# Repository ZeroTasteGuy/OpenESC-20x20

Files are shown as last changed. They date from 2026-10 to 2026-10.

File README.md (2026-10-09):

# OpenESC-20x20

A 4-in-1 sensorless BLDC ESC for the **20 x 20 mm** FPV stack hole pattern: four
independent motor controllers, each with its own MCU, gate driver and six
MOSFETs, running AM32 and taking DShot over a standard 8-pin connector.

> **Status: placement only.** All parts are placed, but there is **no copper and
> no routing**. The board has not been routed, fabricated or tested. Do not
> order it. See [Known issues](#known-issues).

<p>
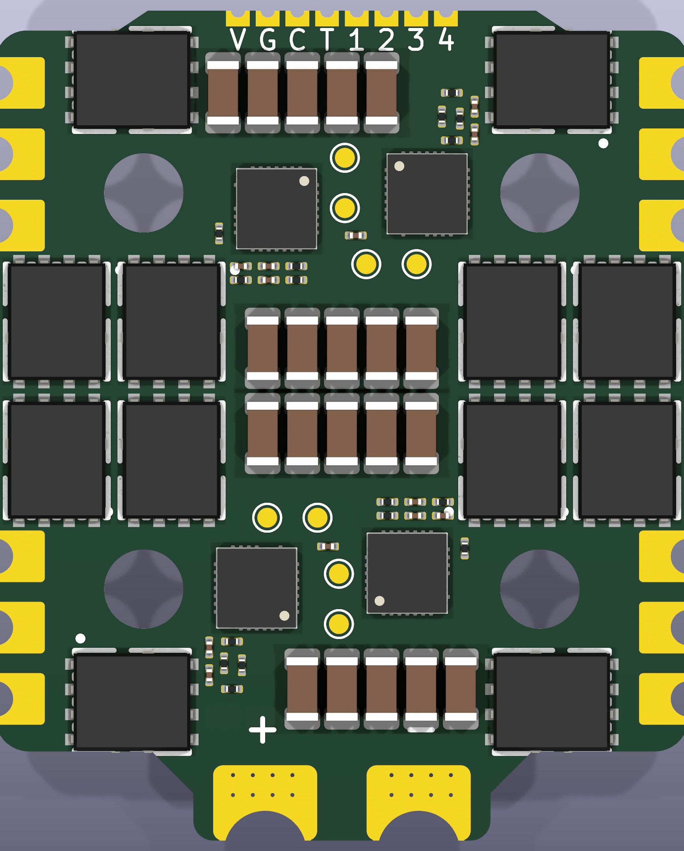
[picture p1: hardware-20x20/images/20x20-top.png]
OpenESC-20x20 top

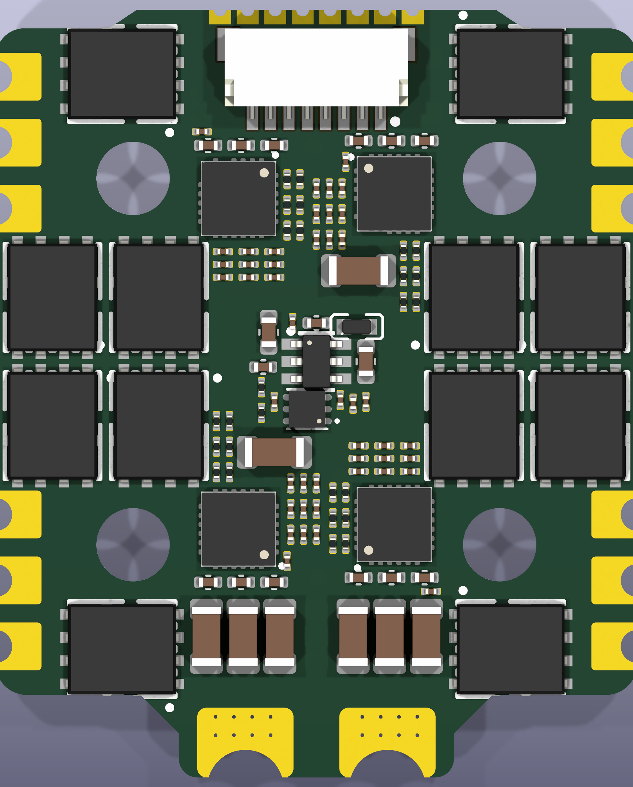
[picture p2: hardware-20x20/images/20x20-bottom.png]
OpenESC-20x20 bottom

</p>

3D views: [top](hardware-20x20/images/20x20-3d-top.png),
[bottom](hardware-20x20/images/20x20-3d-bottom.png).

This is a new PCB layout of the circuit from
[OpenDrone-hw/OpenESC-30x30](https://github.com/OpenDrone-hw/OpenESC-30x30)
(CERN-OHL-S-2.0, maintainer [@Just4Stan](https://github.com/Just4Stan)). The
outline and layout are new, and this board **does not include the current-sense
circuit** (see below); the schematic was edited to match. It is not an official
OpenDrone or Incutec release and is not covered by the upstream OSHWA
certification.

## What changed from the 30x30

| | 30x30 (upstream) | 20x20 (this layout) |
|---|---|---|
| Mounting holes | 30.5 mm pattern | 20 x 20 mm, 4 mm unplated, no copper ring |
| Board size | 30.5 mm class | about 35 x 42 mm including battery tab |
| Layers / copper | 6 layers, 1.6 mm, 2 oz outer / 1 oz inner | same (rules in `4in1.kicad_pro` and `4in1.kicad_dru`) |
| Motor pads | per upstream | corner groups, 3 pads per motor, no notch mid-edge |
| MOSFETs | 24 | 24, as 12 stacked pairs (high side top, low side bottom) |
| Bulk ceramic 1206 | 52 | **28**, on top near the MOSFETs |
| Battery pads | per upstream | two castellated pads on a tab, 4 mm wide x 1.5 mm deep |
| MCU, drivers, critical passives | per upstream | bottom side |
| Programming pads | per upstream | 2.54 mm pitch with hand-rework clearance |
| Current sense | INA186 + 2 shunts, board level | **not on this board** |

Fewer bulk capacitors means less local ripple filtering; install the 470 uF 50 V
electrolytic on the battery leads. Current capacity of this layout is **not**
validated; four channels at 60 A through a board this size is not realistic. See
[hardware-20x20/docs/DESIGN-NOTES.md](hardware-20x20/docs/DESIGN-NOTES.md).

## Specifications (circuit, as upstream)

| | |
|---|---|
| Firmware | AM32 |
| ESC protocol | DShot, bidirectional |
| Telemetry | Extended DShot |
| Input | 2-8S LiPo (6.0-33.6 V) |
| BEC | None |
| Rated current | 60 A / channel in the 30x30 design; **not established for this layout** |

## Architecture

Four independent channels share one power input and one connector. Per channel:
an **AT32F421G8U7** (Cortex-M4, QFN-28) drives an **NSG2065Q** three-phase
half-bridge gate driver, which drives six **SP40N01GHNK** MOSFETs, two per
phase. One channel is drawn once in `ESC.kicad_sch` and instantiated four times.

**There is no current sensing on this board.** The upstream design has a board-level
INA186A3IDCKR across two 0.2 mOhm shunts, reported as `/CURR`. That circuit is
not placed here and was removed from the schematic: U12, Rsense1, Rsense2, R89,
R90, C40, C41, C42, C94 and R73. No per-phase shunts were added either. The
battery pad (U3 pin 1) now connects straight to `+BATT`. `/CURR` (connector pin 3)
is kept as a net but is not driven.

## Power

```
Battery + (2S-8S) ─► +BATT
+BATT ─┬─► MOSFET drains, motor phases
       └─► LMR54406DBVR buck ─► +10V ─┬─► 4x gate driver
                                      └─► TLV76733DRVR ─► +3V3 ─► 4x MCU
```

## Key parts

| Function | Ref | Part | LCSC | Note |
|---|---|---|---|---|
| Motor MCU, x4 | U2, U5, U7, U9 | AT32F421G8U7, QFN-28 | C2765098 | One per channel |
| Gate driver, x4 | U4, U6, U8, U10 | NSG2065Q, QFN-24 | C41414478 | Standard footprint, alternatives exist |
| Power MOSFET, x24 | Q1-Q24 | SP40N01GHNK, PDFN-8L 5x6 | C22385416 | 40 V, 6 per channel; standard 5x6 DFN footprint |
| Buck | U13 | LMR54406DBVR, SOT-23-6 | C5219316 | 1.1 MHz, 0.6 A; FB 115k/10k against 0.8 V for 10.0 V out |
| Buck inductor | U14 | FTC160808S4R7MBCA | C46594347 | 4.7 uH |
| LDO | U15 | TLV76733DRVR, WSON-6 | C2848334 | +10 V to +3V3 |
| Connector | J1 | SM08B-SRSS-TB, JST SH 8-pin | C160407 | Also broken out as castellated pads |
| Bulk electrolytic | / | 470 uF 50 V | / | Installed by the user on the battery leads |
| Bulk ceramic | see PCB | 4.7 uF 1206, X5R 50 V | C380366 | 28 fitted on this layout |

## Connectors and I/O

Betaflight standard 8-pin:

| Pin | Net | Function |
|---|---|---|
| 1 | +BATT | Battery positive |
| 2 | GND | Ground |
| 3 | /CURR | Current sense output; **not driven on this board** (no INA186 fitted) |
| 4 | unconnected | See below |
| 5 | /M1 | DShot, channel 1 |
| 6 | /M2 | DShot, channel 2 |
| 7 | /M3 | DShot, channel 3 |
| 8 | /M4 | DShot, channel 4 |

Pin 4 is the dedicated telemetry pin in the Betaflight 8-pin standard and is
intentionally left unconnected: ESC to FC telemetry rides the motor signal lines
over bidirectional extended DShot instead.

## Layout rules

Bulk decoupling on +BATT and GND exists on the PCB without matching schematic
symbols. That is a deliberate board-only bank. Do not run update-from-schematic
without checking what it would delete.

## Firmware

[AM32](https://github.com/am32-firmware/AM32). Load the bootloader
(`AM32_F421_BOOTLOADER_PB4_V19.hex`) first with an ST-LINK, then flash and
configure the firmware in-browser at [am32.ca](https://am32.ca). Works with
Betaflight and any other DShot-capable flight controller.

## Repository

| | |
|---|---|
| Designed in | KiCad 10 |
| KiCad project | `hardware-20x20/4in1.kicad_pro` (name kept from upstream) |
| Schematics | `hardware-20x20/4in1.kicad_sch` (power, connectors, board block U3, castellated strip J2) plus `ESC.kicad_sch` (one channel, instantiated 4x, unchanged from upstream) |
| Board | `hardware-20x20/4in1.kicad_pcb`, 6 layers, 1.6 mm, 2 oz outer / 1 oz inner copper |
| Board setup | 0.09 mm clearance and track, 0.16 mm on outer layers (2 oz), via 0.35 on 0.20 drill |
| Design rules | `hardware-20x20/4in1.kicad_dru` |
| Local libraries | `components.kicad_sym`, `4in1ESC-30x30.pretty/`, `4in1ESC-30x30.3dshapes/` (only the models in use), inherited from upstream |
| Fab config | `hardware-20x20/fabrication-toolkit-options.json` |
| Renders | `hardware-20x20/images/` |
| Design notes | `hardware-20x20/docs/DESIGN-NOTES.md` |
| Last DRC | `hardware-20x20/docs/drc-v15-placement.json` |
| Placement scripts | `hardware-20x20/tools/` (provenance only, see its README) |
| License | CERN-OHL-S-2.0, see [LICENSE](LICENSE) |

## Checks

```sh
kicad-cli sch erc hardware-20x20/4in1.kicad_sch
kicad-cli pcb drc --schematic-parity --refill-zones hardware-20x20/4in1.kicad_pcb
```

Last DRC run (`docs/drc-v15-placement.json`, without schematic parity): no
clearance or annular-ring errors after the castellated pad fix (the project has
`copper_edge_clearance` set to ignore; with it on, 4 hits remain on the battery
tab, see `hardware-20x20/docs/DESIGN-NOTES.md`); 29
`lib_footprint_mismatch` (to be cleared by re-saving footprints from KiCad
against the local library); 472 unconnected items because nothing is routed.

With schematic parity and ERC (KiCad 10, run on this schematic and board):

- Parity: every schematic part is on the board, and J2 matches except for its
  value and BOM flag (see Known issues). 25 footprints are
  board-only (the CB bulk caps, kept board-only as upstream does). 16
  `net_conflict` notes on IC pads and a J2 pad 4 net name are inherited from
  upstream and the board's footprints. About 146 field mismatches are metadata
  only (Manufacturer fields blank on the board).
- ERC: 18 `pin_not_driven` errors (was 24 upstream) and 4
  `power_pin_not_driven` (was 3). Two of those four appeared because the removed
  U3 power-output pins no longer drive `+BATT` and `GND`; adding a PWR_FLAG on
  each net clears them.

KiCad files cannot be merged. Close KiCad before any scripted write to a KiCad
file, and do not text-edit `.kicad_sch`, `.kicad_pcb` or `.kicad_dru`.

## Known issues

- **Schematic edits to finish.** Add a PWR_FLAG on `+BATT` and `GND` to clear two
  new ERC errors, and set J2's value to "Castellated FC pads" with Exclude from
  BOM ticked so it matches the board footprint exactly.
- **No current sensing.** Removed on purpose (see Architecture). The ESC reports no
  current telemetry; `/CURR` is undriven.
- No copper, planes, vias or tracks. Routing, power-plane design and a current
  and thermal check are all still to do.
- The castellated pads need the fab to accept half-plated holes of this size.
- Some small parts sit in tight clusters (0.2 to 0.3 mm gaps). An earlier
  routing attempt on a related layout failed mostly on boxed-in pads, so expect
  to spread parts or route by hand.
- Silkscreen text may still carry upstream naming; review before any fab export.

## Revisions

| Rev | Date | Change |
|---|---|---|
| v15 | 2026-10-08 | Placement only: 28 bulk caps with fab-safe spacing, battery castellation pads run to the edge, J2 silk labels 1.0 mm. No copper. |
| v15a | 2026-10-08 | Castellated motor and signal pads widened to 5 mm (clears the annular-width DRC errors). Schematic matched to the board: current-sense circuit removed, castellated strip J2 added, U3 board block redrawn as the real outline with only the pins that have pads. |

Upstream revision history (30x30 Rev1 to Rev3.3) is in the
[OpenESC-30x30 repository](https://github.com/OpenDrone-hw/OpenESC-30x30).

## Credit and licence

CERN-OHL-S-2.0, same as upstream. Original circuit and 30x30 design by the
OpenDrone / Incutec team, maintainer @Just4Stan. The 20x20 board layout is a
modified version; changes are limited to PCB outline and placement as described
above. Upstream branding, badges and certification do not carry over to this
layout.

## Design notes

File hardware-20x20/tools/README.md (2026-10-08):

# tools

Python and shell scripts used to generate and check the 20x20 placement
(outline and pads, MOSFET sites, IC and bulk-cap placement, small-part
optimiser, DRC wrapper, an experimental grid router and a copper-path resistance
solver).

Provenance only. They were developed on Windows against `kicad-cli` from KiCad
10 and expect local working copies and intermediate boards that are not in this
repository (for example `../hardware-alt/4in1.kicad_pcb` as the source layout).
Each script rewrites KiCad board text, so run them on copies, never on files in
`hardware-20x20/`. Upstream rules apply: close KiCad before
writing any KiCad file.

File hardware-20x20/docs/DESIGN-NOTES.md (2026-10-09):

# 20x20 layout: design notes

Why the board looks the way it does, and what is known and unknown. Revision
history of the layout lives in git; this file is the intent.

## Goals

- Fit the existing OpenESC circuit on a 20 x 20 mm stack pattern, about 35 x 42 mm.
- Layout in the style of common 20x20 4-in-1 ESCs: motor pads in corner groups
  (3 per motor), no notch in the middle of the long edges, stacked MOSFET pairs.
- Keep the circuit the same except where the layout forced a change (see below).

## Placement

- **Holes:** 4 mm unplated at (+-10, +-10) mm. A 6 mm rubber-grommet zone around
  each hole keeps small parts out.
- **MOSFETs:** 12 sites, each a stacked pair on the same x/y (high side on top,
  low side on the bottom): 4 corner pairs (phase A) and 8 strip pairs (phases B
  and C, inner and edge columns). Upper-half sites are rotated 0 degrees, lower
  half 180 degrees.
- **Bottom side:** MCUs, gate drivers, buck, LDO and critical passives (gate
  resistors, bootstrap and supply decoupling).
- **Top side:** MOSFETs, 28 bulk 1206 capacitors, test points and a few
  non-critical parts.
- **Symmetry:** the two half-boards are 180 degree twins.
- **Battery tab:** two castellated pads 4 mm wide and 1.5 mm deep with rounded
  tab corners; a bulk-cap row sits directly above it.
- **Castellation convention:** the motor pads (U3 pads 12 to 23) and the J2 strip
  are centred on their plated hole, with the hole on the board edge and no drill
  offset. The pads are 5 x 2.6 mm (motor) and 1.2 x 1.6 mm (J2), so 2.5 mm and
  0.8 mm of copper lie inside the board; the outer half hangs past the outline
  and is milled away by the fab. An earlier version put the pad on the edge with
  the drill offset inboard, which missed the Edge.Cuts half-hole notch and gave
  zero annular width. The battery castellations were already consistent (hole
  centre 0.58 mm outside the edge, 1.5 mm deep notch).
- **Known DRC note:** the project sets `copper_edge_clearance` to ignore. With it
  enabled there are 4 hits on the battery tab, where the pad copper meets the
  outline beside each notch (near x 69.1 and 73.725, y 70.05). Accepted for now;
  confirm with the fab.
- **Keep-outs used:** small ICs and passives at least 3 mm from motor and battery
  pads and 2 mm from the board edge. MOSFETs, the JST connector and 1206 caps may
  sit closer. Bulk-cap pad gaps are at least 0.2 mm for fab safety.
- **No current sensing at all.** The board-level INA186 (U12), its two shunts
  (Rsense1, Rsense2) and the input network (R89, R90, C40, C41, C42, plus C94 and
  R73) are not on the PCB, and per-phase shunts were not wanted either. They
  were removed from the schematic so it matches the board.
- **Schematic matched to the board:** castellated strip J2 added (pins +BATT,
  GND, CURR, unused, M1 to M4); the U3 board block lost the pins that no longer
  have pads (3 to 11) and was redrawn with the real board outline (chamfered
  top strip, bottom battery tab, four mounting holes); the battery pad (U3 pin 1)
  joins `+BATT` directly where the shunts used to sit.

## Findings

- **Bottom free area is the bottleneck.** About 391 mm2 of 1345 mm2 is free for
  small parts after MOSFETs, pad keep-outs, grommet zones and the edge band.
- **Copper-only path resistance** (estimated on an earlier placement with power
  copper, ESC1, source-to-pad / pad-to-drain, mOhm): phase A 0.18 / 0.14,
  B 0.06 / 0.03, C 0.61 / 0.48. Worst point: low-side ground path of phase B
  (about 2 mOhm, no ground vias yet) and the narrow phase-C lane between hole and
  MOSFET row. This was **not** repeated on the final placement.
- **Current capacity:** lane necks reached about 45 A/mm at 40 A in an earlier
  trial; about 8 to 10 A/mm is comfortable for 2 oz outer copper. Do not expect
  four channels at 60 A.
- **Signal routing:** an automatic grid router completed about a third of the
  links on the related layout, and most failures were pads boxed in by
  neighbours. Spacing, not copper weight, is the limit.

## To do before this can be a real board

0. Add a PWR_FLAG on `+BATT` and `GND`, set J2's value and BOM flag to match the
   board, then re-run ERC and DRC with schematic parity.
1. Power copper: planes, phase copper, via sets, ground vias at low-side sources.
2. Signal routing, mostly by hand.
3. Re-run DRC with schematic parity and ERC, resolve `lib_footprint_mismatch`.
4. Resistance and thermal check on the routed board.
5. Confirm castellation capability with the intended fab.
6. Rename the archive in `fabrication-toolkit-options.json`, review silkscreen.
7. Bring-up with a current-limited supply before any motor.

## Regenerating

`tools/` holds the scripts that produced the placement. They were run against
local working copies that are not in this repository, so treat them as
documentation of the method rather than a reproducible build. See
`tools/README.md`.

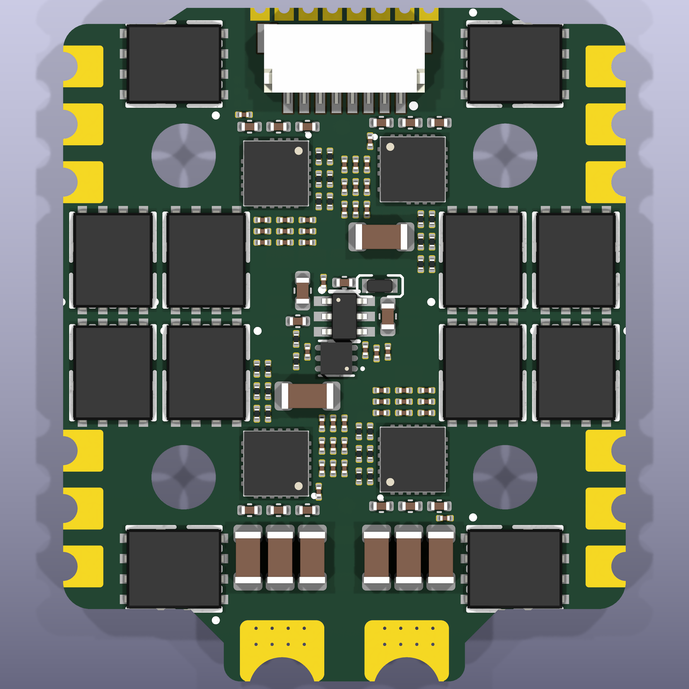
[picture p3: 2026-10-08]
hardware-20x20/images/20x20-3d-bottom.png

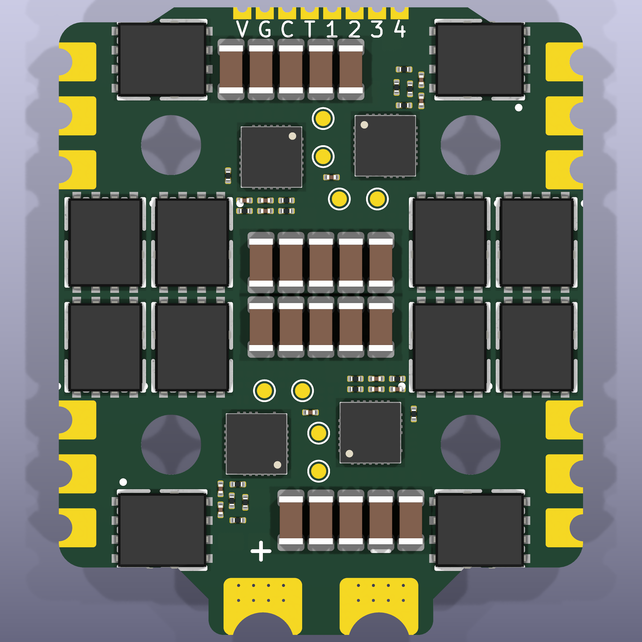
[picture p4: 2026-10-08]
hardware-20x20/images/20x20-3d-top.png

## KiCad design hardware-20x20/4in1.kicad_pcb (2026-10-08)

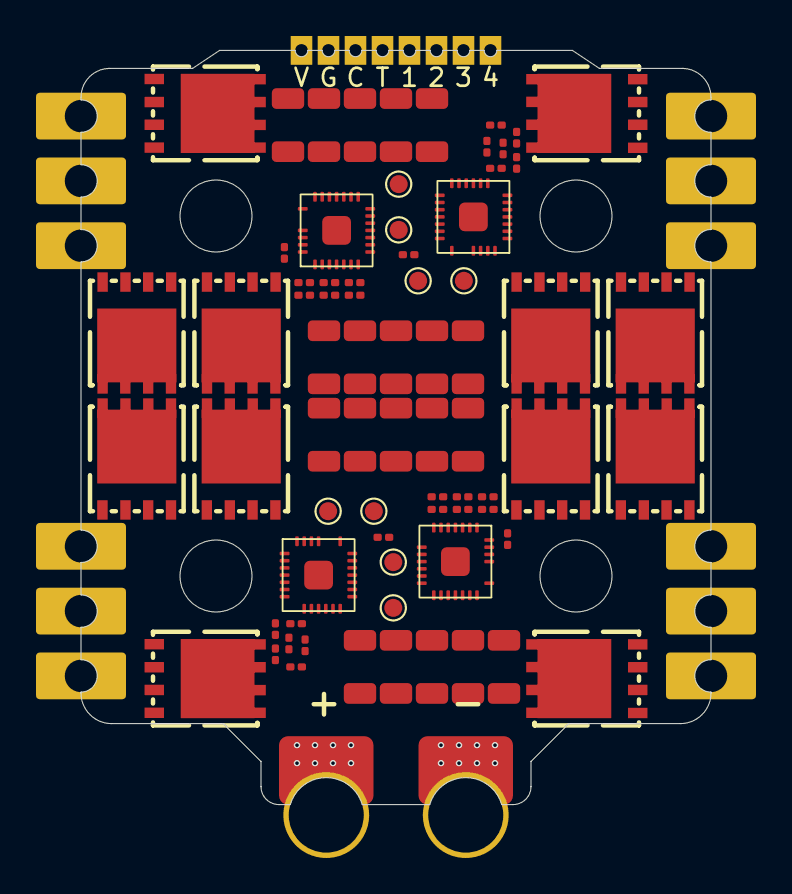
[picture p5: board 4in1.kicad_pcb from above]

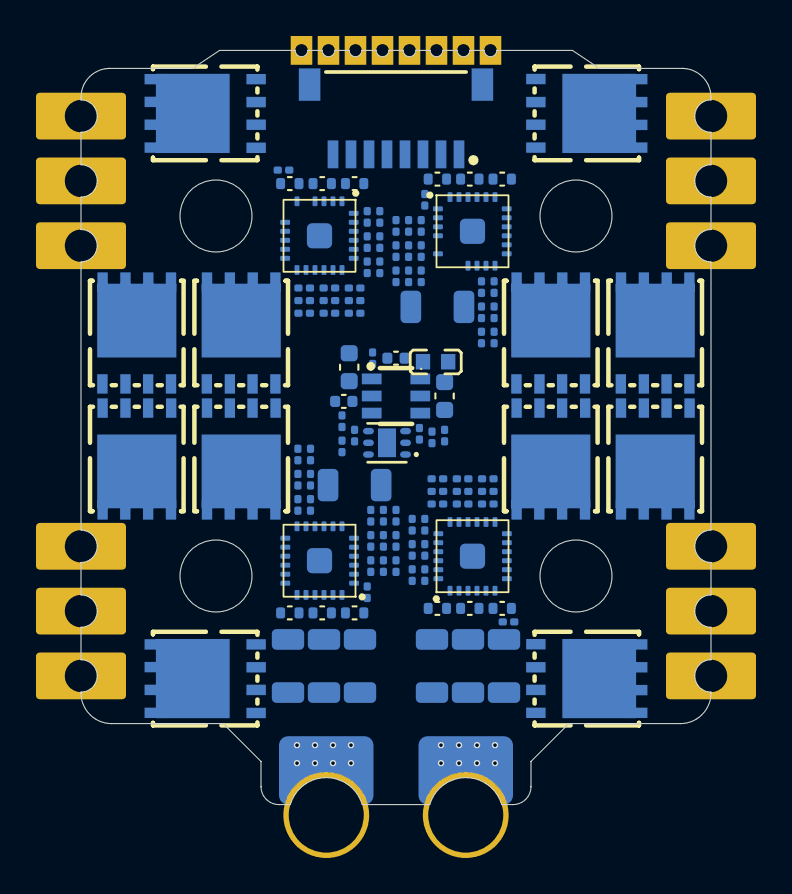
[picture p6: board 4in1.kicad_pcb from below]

Board: 6 copper layers, 35.0 x 41.9 mm, 189 parts (115 on the bottom side), 148 nets, no tracks yet.

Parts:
C2, C3, C6: 4.7uF; C_1206_3216Metric
C4, C51: 22uF; C_0402_1005Metric
C32, C33, C34, C35, C36, C37, C38, C39, C53, C56, C62, C67: 100nF; C_0402_WIDE
C47, C86: 22uF; C_0603_1608Metric
C48, C49, C50, C52, C54, C55, C57, C58, C59, C60, C61, C63, C64, C65, C66, C68, C74, C75, C76, C81, C93: 100nF; C_0201_0603Metric
CB1, CB2, CB3, CB4, CB5, CB6, CB7, CB8, CB9, CB10, CB11, CB12, CB13, CB15, CB19, CB20, CB21, CB25, CB26, CB28, CB29, CB30, CB31, CB32, CB33: 4.7uF; C_1206_3216Metric
J1: SM08B-SRSS-TB; JST_SM08B-SRSS-TB
J2: Castellated FC pads; Castellated_8x1.50
Q1, Q2, Q3, Q4, Q5, Q6, Q7, Q8, Q9, Q10, Q11, Q12, Q13, Q14, Q15, Q16, Q17, Q18, Q19, Q20, Q21, Q22, Q23, Q24: SP40N01GHNK; PDFN-8L_L6.0-W5.0-P1.27
R10, R12, R13, R15, R25, R27, R28, R30, R31, R33, R34, R36, R46, R48, R49, R51, R52, R54, R64, R66, R67, R69, R70, R72: 10k; C_0201_0603Metric
R11, R14, R26, R29, R32, R35, R47, R50, R53, R65, R68, R71: 1k; C_0201_0603Metric
R18, R19, R21, R22, R40, R41, R58, R59, R121: 10k; R_0201_0603Metric
R20, R39, R57, R87: 220R; R_0201_0603Metric
R23, R24, R37, R38, R42, R43, R44, R45, R55, R56, R60, R61, R62, R63, R74, R75, R76, R77, R78, R79, R80, R81, R82, R83: 15R; R_0201_0603Metric
R84, R85, R86, R88: 10R; R_0201_0603Metric
R120: 115k; R_0201_0603Metric
TP1, TP2, TP3, TP4, TP5, TP6, TP7, TP8: TestPoint; TestPoint_Pad_D1.0mm
U2, U5, U7, U9: AT32F421G8U7; QFN-28_L4.0-W4.0-P0.40-TL-EP2.4
U3: 4in1ESC30x30
U4, U6, U8, U10: NSG2065Q; QFN-24_L4.0-W4.0-P0.50-TL-EP2.8
U13: LMR54406DBVR; SOT-23-6_L2.9-W1.6-P0.95-LS2.8-BR
U14: FTC160808S4R7MBCA; IND-SMD_L1.6-W0.8_FTC160865SR47MBCA
U15: TLV76733DRVR; WSON-6_L2.0-W2.0-P0.65-TL-EP

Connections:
+3V3: C4.2, C49.1, C51.2, C55.1, C61.1, C66.1, C81.1, C93.1, R18.2, R21.2, R40.2, R58.2, R84.2, R85.2, R86.2, R88.2, U2.17 (VDD), U5.17 (VDD), U7.17 (VDD), U9.17 (VDD), U15.1 (OUT), U15.2 (FB/SNS)
+10V: C47.1, C57.1, C58.1, C63.1, C68.1, C76.1, C86.1, R120.1, U4.4 (VCC), U6.4 (VCC), U8.4 (VCC), U10.4 (VCC), U14.2, U15.4 (EN), U15.6 (IN)
+BATT: C2.1, C3.1, C6.1, C74.1, CB1.1, CB2.1, CB3.1, CB4.1, CB5.1, CB6.1, CB7.1, CB8.1, CB9.1, CB10.1, CB11.1, CB12.1, CB13.1, CB15.1, CB19.1, CB20.1, CB21.1, CB25.1, CB26.1, CB28.1, CB29.1, CB30.1, CB31.1, CB32.1, CB33.1, J1.1, J2.1 (VCC), Q1.3 (D), Q6.3 (D), Q7.3 (D), Q8.3 (D), Q9.3 (D), Q10.3 (D), Q13.3 (D), Q16.3 (D), Q17.3 (D), Q18.3 (D), Q19.3 (D), Q20.3 (D), U3.1, U13.4 (EN), U13.5 (VIN)
/CURR: J1.3, J2.3 (CUR)
/ESC1/AH: U2.20 (PA10), U4.22 (HIN1)
/ESC1/AL: U2.15 (PB1), U4.1 (LIN1)
/ESC1/BH: U2.19 (PA9), U4.23 (HIN2)
/ESC1/BL: U2.14 (PB0), U4.2 (LIN2)
/ESC1/CH: U2.18 (PA8), U4.24 (HIN3)
/ESC1/CL: U2.13 (PA7), U4.3 (LIN3)
/ESC1/FBA: R25.1, R26.2, R27.2, U2.6 (PA0)
/ESC1/FBB: R28.2, R29.2, R30.2, U2.10 (PA4)
/ESC1/FBC: R31.2, R32.2, R33.2, U2.11 (PA5)
/ESC1/FBCOMMON: R25.2, R28.1, R31.1, U2.7 (PA1)
/ESC1/GHA: R76.1, U4.19 (HO1)
/ESC1/GHB: R55.1, U4.16 (HO2)
/ESC1/GHC: R23.1, U4.13 (HO3)
/ESC1/GLA: R80.1, U4.11 (LO1)
/ESC1/GLB: R62.1, U4.10 (LO2)
/ESC1/GLC: R42.1, U4.9 (LO3)
/ESC1/MotorA: C53.1, Q1.1 (S), Q2.3 (D), R27.1, U3.23, U4.18 (VS1)
/ESC1/MotorB: C32.1, Q6.1 (S), Q11.3 (D), R30.1, U3.22, U4.15 (VS2)
/ESC1/MotorC: C36.1, Q16.1 (S), Q21.3 (D), R33.1, U3.21, U4.12 (VS3)
/ESC1/vdda: C48.1, R84.1, U2.5 (VDDA)
/ESC2/AH: U5.20 (PA10), U6.22 (HIN1)
/ESC2/AL: U5.15 (PB1), U6.1 (LIN1)
/ESC2/BH: U5.19 (PA9), U6.23 (HIN2)
/ESC2/BL: U5.14 (PB0), U6.2 (LIN2)
/ESC2/CH: U5.18 (PA8), U6.24 (HIN3)
/ESC2/CL: U5.13 (PA7), U6.3 (LIN3)
/ESC2/FBA: R10.1, R11.2, R12.2, U5.6 (PA0)
/ESC2/FBB: R13.2, R14.2, R15.2, U5.10 (PA4)
/ESC2/FBC: R34.2, R35.2, R36.2, U5.11 (PA5)
/ESC2/FBCOMMON: R10.2, R13.1, R34.1, U5.7 (PA1)
/ESC2/GHA: R77.1, U6.19 (HO1)
/ESC2/GHB: R56.1, U6.16 (HO2)
/ESC2/GHC: R24.1, U6.13 (HO3)
/ESC2/GLA: R81.1, U6.11 (LO1)
/ESC2/GLB: R63.1, U6.10 (LO2)
/ESC2/GLC: R43.1, U6.9 (LO3)
/ESC2/MotorA: C56.1, Q3.3 (D), Q7.1 (S), R12.1, U3.20, U6.18 (VS1)
/ESC2/MotorB: C33.1, Q8.1 (S), Q12.3 (D), R15.1, U3.19, U6.15 (VS2)
/ESC2/MotorC: C37.1, Q17.1 (S), Q22.3 (D), R36.1, U3.18, U6.12 (VS3)
/ESC2/vdda: C54.1, R85.1, U5.5 (VDDA)
/ESC3/AH: U7.20 (PA10), U8.22 (HIN1)
/ESC3/AL: U7.15 (PB1), U8.1 (LIN1)
/ESC3/BH: U7.19 (PA9), U8.23 (HIN2)
/ESC3/BL: U7.14 (PB0), U8.2 (LIN2)
/ESC3/CH: U7.18 (PA8), U8.24 (HIN3)
/ESC3/CL: U7.13 (PA7), U8.3 (LIN3)
/ESC3/FBA: R46.1, R47.2, R48.2, U7.6 (PA0)
/ESC3/FBB: R49.2, R50.2, R51.2, U7.10 (PA4)
/ESC3/FBC: R52.2, R53.2, R54.2, U7.11 (PA5)
/ESC3/FBCOMMON: R46.2, R49.1, R52.1, U7.7 (PA1)
/ESC3/GHA: R78.1, U8.19 (HO1)
/ESC3/GHB: R60.1, U8.16 (HO2)
/ESC3/GHC: R37.1, U8.13 (HO3)
/ESC3/GLA: R82.1, U8.11 (LO1)
/ESC3/GLB: R74.1, U8.10 (LO2)
/ESC3/GLC: R44.1, U8.9 (LO3)
/ESC3/MotorA: C62.1, Q4.3 (D), Q13.1 (S), R48.1, U3.15, U8.18 (VS1)
/ESC3/MotorB: C34.1, Q9.1 (S), Q14.3 (D), R51.1, U3.16, U8.15 (VS2)
/ESC3/MotorC: C38.1, Q18.1 (S), Q23.3 (D), R54.1, U3.17, U8.12 (VS3)
/ESC3/vdda: C60.1, R86.1, U7.5 (VDDA)
/ESC4/AH: U9.20 (PA10), U10.22 (HIN1)
/ESC4/AL: U9.15 (PB1), U10.1 (LIN1)
/ESC4/BH: U9.19 (PA9), U10.23 (HIN2)
/ESC4/BL: U9.14 (PB0), U10.2 (LIN2)
/ESC4/CH: U9.18 (PA8), U10.24 (HIN3)
/ESC4/CL: U9.13 (PA7), U10.3 (LIN3)
/ESC4/FBA: R64.1, R65.2, R66.2, U9.6 (PA0)
/ESC4/FBB: R67.2, R68.2, R69.2, U9.10 (PA4)
/ESC4/FBC: R70.2, R71.2, R72.2, U9.11 (PA5)
/ESC4/FBCOMMON: R64.2, R67.1, R70.1, U9.7 (PA1)
/ESC4/GHA: R79.1, U10.19 (HO1)
/ESC4/GHB: R61.1, U10.16 (HO2)
/ESC4/GHC: R38.1, U10.13 (HO3)
/ESC4/GLA: R83.1, U10.11 (LO1)
/ESC4/GLB: R75.1, U10.10 (LO2)
/ESC4/GLC: R45.1, U10.9 (LO3)
/ESC4/MotorA: C67.1, Q5.3 (D), Q19.1 (S), R66.1, U3.12, U10.18 (VS1)
/ESC4/MotorB: C35.1, Q10.1 (S), Q15.3 (D), R69.1, U3.13, U10.15 (VS2)
/ESC4/MotorC: C39.1, Q20.1 (S), Q24.3 (D), R72.1, U3.14, U10.12 (VS3)
/ESC4/vdda: C65.1, R88.1, U9.5 (VDDA)
/M1: J1.5, J2.5 (S1), R20.1
/M2: J1.6, J2.6 (S2), R39.1
/M3: J1.7, J2.7 (S3), R57.1
/M4: J1.8, J2.8 (S4), R87.1
GND: C2.2, C3.2, C4.1, C6.2, C47.2, C48.2, C49.2, C50.2, C51.1, C52.2, C54.2, C55.2, C57.2, C58.2, C59.2, C60.2, C61.2, C63.2, C64.2, C65.2, C66.2, C68.2, C74.2, C76.2, C81.2, C86.2, C93.2, CB1.2, CB2.2, CB3.2, CB4.2, CB5.2, CB6.2, CB7.2, CB8.2, CB9.2, CB10.2, CB11.2, CB12.2, CB13.2, CB15.2, CB19.2, CB20.2, CB21.2, CB25.2, CB26.2, CB28.2, CB29.2, CB30.2, CB31.2, CB32.2, CB33.2, J1.2, J1.P1 (MP1), J1.P2 (MP2), J2.2 (GND), Q2.1 (S), Q3.1 (S), Q4.1 (S), Q5.1 (S), Q11.1 (S), Q12.1 (S), Q14.1 (S), Q15.1 (S), Q21.1 (S), Q22.1 (S), Q23.1 (S), Q24.1 (S), R11.1, R14.1, R19.2, R22.2, R26.1, R29.1, R32.1, R35.1, R41.2, R47.1, R50.1, R53.1, R59.2, R65.1, R68.1, R71.1, R121.2, U2.16 (VSS), U2.29 (VSS), U3.2, U4.6 (COM), U4.25 (COM), U5.16 (VSS), U5.29 (VSS), U6.6 (COM), U6.25 (COM), U7.16 (VSS), U7.29 (VSS), U8.6 (COM), U8.25 (COM), U9.16 (VSS), U9.29 (VSS), U10.6 (COM), U10.25 (COM), U13.2 (GND), U15.3 (GND), U15.5 (GND), U15.7 (EP)
unnamed: Q1.2 (G), R76.2
unnamed: Q2.2 (G), R80.2
unnamed: Q3.2 (G), R81.2
unnamed: Q4.2 (G), R82.2
unnamed: Q5.2 (G), R83.2
unnamed: Q6.2 (G), R55.2
unnamed: Q7.2 (G), R77.2
unnamed: Q8.2 (G), R56.2
unnamed: Q9.2 (G), R60.2
unnamed: Q10.2 (G), R61.2
unnamed: Q11.2 (G), R62.2
unnamed: Q12.2 (G), R63.2
unnamed: Q13.2 (G), R78.2
unnamed: Q14.2 (G), R74.2
unnamed: Q15.2 (G), R75.2
unnamed: Q16.2 (G), R23.2
unnamed: Q17.2 (G), R24.2
unnamed: Q18.2 (G), R37.2
unnamed: Q19.2 (G), R79.2
unnamed: Q20.2 (G), R38.2
unnamed: Q21.2 (G), R42.2
unnamed: Q22.2 (G), R43.2
unnamed: Q23.2 (G), R44.2
unnamed: Q24.2 (G), R45.2
unnamed: R19.1, U2.1 (BOOT0)
unnamed: C50.1, R18.1, U2.4 (NRST)
unnamed: TP1.1 (1_1), U2.21 (PA13)
unnamed: TP4.1 (1_1), U2.22 (PA14)
unnamed: R20.2, U2.25 (PB4)
unnamed: C53.2, U4.20 (VB1)
unnamed: C32.2, U4.17 (VB2)
unnamed: C36.2, U4.14 (VB3)
unnamed: R22.1, U5.1 (BOOT0)
unnamed: C52.1, R21.1, U5.4 (NRST)
unnamed: TP2.1 (1_1), U5.21 (PA13)
unnamed: TP5.1 (1_1), U5.22 (PA14)
unnamed: R39.2, U5.25 (PB4)
unnamed: C56.2, U6.20 (VB1)
unnamed: C33.2, U6.17 (VB2)
unnamed: C37.2, U6.14 (VB3)
unnamed: R41.1, U7.1 (BOOT0)
unnamed: C59.1, R40.1, U7.4 (NRST)
unnamed: TP3.1 (1_1), U7.21 (PA13)
unnamed: TP6.1 (1_1), U7.22 (PA14)
unnamed: R57.2, U7.25 (PB4)
unnamed: C62.2, U8.20 (VB1)
unnamed: C34.2, U8.17 (VB2)
unnamed: C38.2, U8.14 (VB3)
unnamed: R59.1, U9.1 (BOOT0)
unnamed: C64.1, R58.1, U9.4 (NRST)
unnamed: TP7.1 (1_1), U9.21 (PA13)
unnamed: TP8.1 (1_1), U9.22 (PA14)
unnamed: R87.2, U9.25 (PB4)
unnamed: C67.2, U10.20 (VB1)
unnamed: C35.2, U10.17 (VB2)
unnamed: C39.2, U10.14 (VB3)
unnamed: C75.2, U13.1 (CB)
unnamed: R120.2, R121.1, U13.3 (FB)
unnamed: C75.1, U13.6 (SW), U14.1

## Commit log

2026-10-08 Add 20x20 alternative layout (placement only)
    New hardware-20x20/ folder with the 20 x 20 mm stack-pattern layout of the
    OpenESC circuit: board, unchanged schematics and rules, renders, README,
    design notes, last DRC result and the placement scripts. Library tables
    point at ../hardware so nothing is duplicated. Upstream hardware/ is
    untouched. Root README gets a fork notice.
    [4in1.kicad_pcb, 4in1.kicad_sch, ESC.kicad_sch]
2026-10-08 Make the branch layout-only: remove upstream 30x30 design
    Remove hardware/ (upstream 30x30 board, schematic, library submodule),
    upstream renders, OSHWA badges, AGENTS.md and CONTRIBUTING.md. The 20x20
    project is now self-contained: local footprint library and only the 3D
    models in use are copied into hardware-20x20/, library tables no longer
    point outside it, the OpenDrone submodule is dropped (not used by the
    schematic). Root README rewritten for the 20x20 layout with the circuit
    description, upstream credit and licence kept. Fab archive name set to
    OpenESC-20x20.
    [4in1-panel.kicad_pcb, 4in1.kicad_pcb, 4in1.kicad_sch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]
2026-10-08 docs: board has no current-sense circuit
    U12 (INA186), Rsense1/2, R89, R90, C40-C42, C94 and R73 are in the
    schematic but not on the PCB. Remove them from the key parts table and
    power diagram, mark /CURR as undriven, and list the schematic/board
    mismatch under known issues.
2026-10-08 Fix castellated pad geometry on motor and FC pads
    Pads were centered on the board edge with the drill offset 1.25 mm (motor)
    or 0.4 mm (J2) inboard, so the hole did not line up with the Edge.Cuts
    half-hole notch and DRC reported zero annular width on all 20 pads.
    Center each pad on its hole (hole on the board edge, no drill offset) and
    widen it so the copper inside the board is unchanged (2.5 mm motor, 0.8 mm
    J2). DRC: annular_width 20 -> 0. Add top/bottom renders.
    [4in1.kicad_pcb]
2026-10-08 Refresh renders and DRC report after castellation fix
    Regenerate the top, bottom and 3D renders from the current board (the old 3D
    images showed an earlier routed layout) and replace the DRC report. DRC now
    shows only lib_footprint_mismatch; the 20 annular_width errors are gone. Drop
    the temporary -fixed renders.
2026-10-08 Match the schematic to the board and redraw the U3 block
    Schematic (edited in KiCad 10, netlist diffed against the original):
    - remove the current-sense circuit (U12, Rsense1/2, R89, R90, C40-C42,
    C94, R73) and wire the battery pad straight to +BATT
    - add J2, the 8-pad castellated strip (+BATT, GND, CURR, unused, M1-M4)
    - U3 board block: drop pins 3-11 that no longer have pads and redraw it as
    the real outline (chamfered top strip, battery tab, 4 mounting holes)
    - remove the orphaned labels and wires left by those pins
    Docs: README and design notes updated for the schematic changes, the
    castellation fix and the current ERC and parity results.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
    [4in1.kicad_sch, ESC.kicad_sch]
